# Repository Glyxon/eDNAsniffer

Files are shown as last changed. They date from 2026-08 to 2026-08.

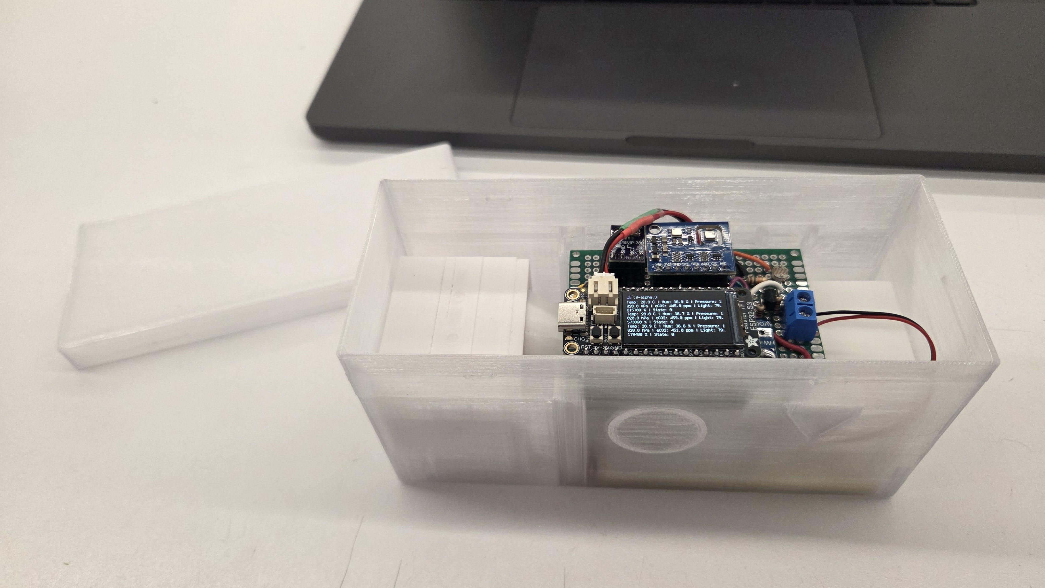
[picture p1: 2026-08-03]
ESP32 Assembly pics/signal-2026-08-01-16-24-59-932_003.jpg

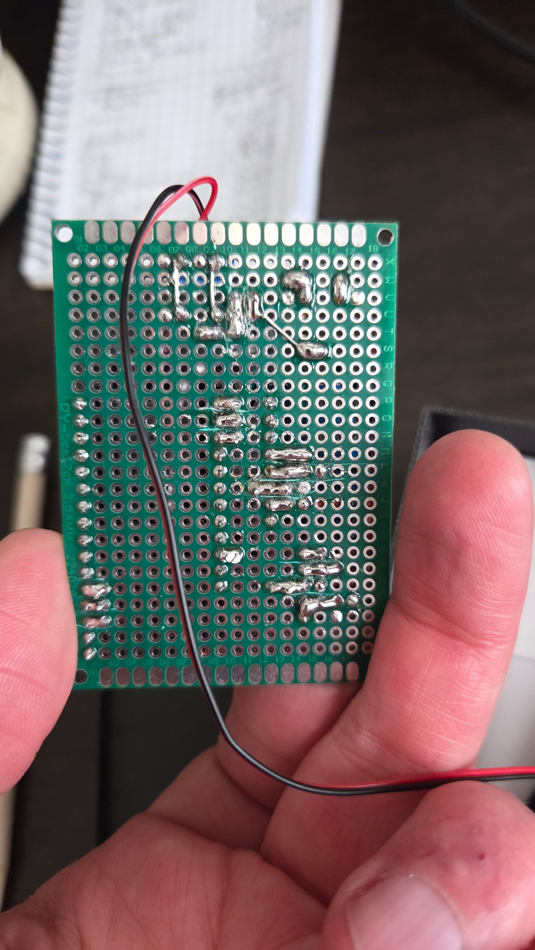
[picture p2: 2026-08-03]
ESP32 Assembly pics/wiring2.jpg

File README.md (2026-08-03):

# eDNA Sniffer (v1.1)

An open-source, low-cost, ESP32-S3/ Rapsberry-Pi powered airborne environmental DNA (eDNA) sampling and monitoring station. 

Developed as part of decentralized biotechnology and open hardware initiatives (Developed by **Glyxon BioLabs** and **BioOlympia**), this project integrates physical air filtration, environmental sensor telemetry (temperature, humidity, pressure, gas quality, and light), and a streamlined molecular biology protocol for downstream 16S rRNA gene amplification and taxonomic profiling. This project is presented at DEFCON 34. 

Contact the creators: 

Dr. David Castillo · glyxonbiolabs@gmail.com  ·  +52 (55) 4140 7607
BioOlympia (Matt + Zee) · BioOlympia@gmail.com  ·  +1 (971) 319-2665



---

## 🛠️ System Overview & Architecture

The eDNA Sniffer combines an **ESP32 microcontroller** (Ideaspark board) with an environmental sensor hub, an air sampling chamber driven by a brushless fan, and an optimized dual-capture physics configuration.

```
[Air Intake] → [Membrane Filter / Fine Mesh] → [3010 Fan] → [Silica Gel Chamber] → [Air Exhaust]
```

**Airflow Diagram (Sampling Enclosure)**



To build the physical collector using your boards and the fan, you need to design or adapt a small airtight container (this could be a 3D-printed enclosure or a modified plastic container):

1.	The fan pulls or pushes outdoor air, forcing it through a small chamber (Venturi collector)  where you position your eDNA collection membrane.
2.	The filtered, dried air then flows past rate is monitored by different sensors (AHT21/BME280 and ENS160) to log precise environmental sampling parameters (humidity, background volatile organic compounds, and temperature).

Implementing a dual-capture mechanism within this Venturi geometry leverages fluid dynamics beautifully to sort particles by size and mass. In aerosol science and environmental sampling, this is conceptually similar to a simplified cascade impactor.
Here is how the physics of this dual-capture setup benefits your eDNA sampling:
1. Intake Pre-Filter (Coarse eDNA Capture)
•	The Mechanism: At the wide base, the air velocity entering from the 3010 fan is relatively slow, but the surface area is at its largest.
•	What it Captures: Large biological vectors such as whole pollen grains, fungal spores, insect fragments, and heavy environmental dust particles that contain cellular material.
•	The Benefit: It acts as a primary filter. If these massive particles reached the narrow throat or the fine filter, they would immediately clog the system (causing severe back pressure) and reduce the sampler's operational lifespan in the field.

2. Venturi Throat / Upper Trap (High-Velocity Fine eDNA Capture)
•	The Mechanism: As the air is forced through the constriction, its velocity peaks.
•	What it Captures: Micro-droplets, fine aerosolized particles, single bacteria, and naked/free-floating extracellular DNA strands bound to microscopic dust (PM2.5 or smaller). The higher momentum allows these tiny particles to be driven forcefully into a fine-pore membrane (like glass fiber or nylon).
•	The Benefit: This is where you isolate the highly integrated, long-range eDNA signals traveling through the air mass rather than just localized debris.
How to Read Sensors in this Dual Setup
By utilizing the different sensor placement options shown in the diagram, you can monitor the physical performance of this dual-capture chamber in real-time with your ESP32:
•	Monitoring Clogging (Differential Pressure): If you place the BME280/BMP280 at Location 2 (Venturi Throat) or Location 1 (Post-Filter), you can track the static pressure drop over time. As filters capture eDNA and start to saturate, the pressure values will shift drastically. When the pressure drop levels off or hits a critical threshold, the ESP32 LCD can alert you that the filters are full and the device has completed its run.
•	Correlating Environmental Data: The ENS160 gas readings (eCO2/TVOC) will help you cross-reference your biological collection with environmental context—letting you know if a high yield of eDNA correlates with sudden spikes in organic volatiles or stale air masses.

### Key Hardware Components











* **Microcontroller:** ESP32-S3 FT Feather  (Adafuit development board with built-in display).
* **Air Sampling Mechanism:** 3010 Brushless Fan (5V) paired with a Venturi geometry sampling chamber.
* **Desiccant Chamber:** Indicating silica gel to maintain low humidity and prevent DNA degradation post-collection.
* **Capture Media:** Nitrocellulose filter paper (0.2 to 1 µm) for fine eDNA trapping, supported by optional bacterial cellulose matrices (`Komagataeibacter xylinus`) can be provided by Glyxon BioLabs if you need some.

2. Sensor Connection Architecture (I2C)
Both the ENS160+AHT21 module and the BME280/BMP280 operate primarily via the I2C communication protocol. This means they can share the same data (SDA) and clock (SCL) lines, drastically simplifying the circuit layout on your green prototyping PCB.
Pin Mapping (ESP32 Ideaspark):
By default, most ESP32 boards configure the I2C protocol on the following pins, though you can redefine them in your Arduino dependencies.

Watch out for I2C addresses! If your pressure chip turns out to be a BMP280 instead of a BME280, keep in mind that its default I2C address usually shifts between 0x76 and 0x77. The ENS160 typically uses address 0x53. They will not collide on the bus.
The LDR (GL5516 Light Sensor):
To measure ambient light, you need to build a voltage divider using one of your 10kΩ resistors. This translates the varying resistance of the LDR into a voltage the ESP32 can read:
1.	Connect one end of the LDR to 3.3V.
2.	Connect the other end of the LDR to an analog pin on the ESP32 (e.g., GPIO 34 or 35).
3.	From that same middle connection point, connect a 10kΩ resistor to GND.

Controlling the Fan (3010 Fan):
The fan runs on 5V. Do not connect it directly to an ESP32 data pin because you will burn out the chip (ESP32 pins only output 3.3V and about 20-40mA).
•	Simple Option: Connect it directly to the 5V/VIN and GND pins on the ESP32 so that it draws air continuously as soon as the system powers up.

---

## 🔌 Wiring & Pin Mapping

Both sensor modules operate on the **I2C protocol**, allowing them to share a common data bus (`SDA` on GPIO 21, `SCL` on GPIO 22).

### Complete Wiring Matrix

| Component | Pin | Connects To (ESP32) | Purpose / Notes |
| :--- | :--- | :--- | :--- |
| **ENS160+AHT21 Module** | `VCC` | `3V3` | 3.3V Power Supply |
| | `GND` | `GND` | Common Ground |
| | `SCL` | `GPIO 22` | I2C Clock Line (Shared) |
| | `SDA` | `GPIO 21` | I2C Data Line (Shared) |
| **BME280/BMP280 Module** | `VCC` | `3V3` | 3.3V Power Supply |
| | `GND` | `GND` | Common Ground |
| | `SCL` | `GPIO 22` | I2C Clock Line (Shared) |
| | `SDA` | `GPIO 21` | I2C Data Line (Shared) |
| **GL5516 Photoresistor (LDR)** | `Pin 1` | `3V3` | Voltage Source |
| | `Pin 2` | `GPIO 34` | Analog Input & Divider Junction |
| **10kΩ Resistor** | `Lead A` | `GPIO 34` | Connected to Ldr Pin 2 |
| | `Lead B` | `GND` | Pulls signal to Ground |
| **3010 Brushless Fan (5V)** | `Red Wire` | `5V / VIN` | Direct power from USB/Power Bank source |
| | `Black Wire` | `GND` | Continuous ground connection |

> ⚠️ **Important Safety Check:** Keep the 5V brushless fan strictly connected to the `5V / VIN` pin. Connecting 5V inductive loads directly to the 3.3V digital rail can permanently damage the ESP32 internal voltage regulator.

---

## 💻 Firmware & Arduino IDE Setup

Basic Code Logic (Arduino IDE)
For ESP32 boards with built-in LCD screens, you will need to install these libraries from the Arduino Library Manager:
•	Adafruit BME280 Library (or BMP280)
•	ScioSense_ENS160 (for the advanced air quality sensor)
•	Specific graphics libraries for your Ideaspark display (usually TFT_eSPI or Adafruit_GFX, depending on the exact LCD model it uses).

### Required Libraries
Install the following libraries via the Arduino Library Manager:
1. `Adafruit BME280 Library` (or BMP280)
2. `ScioSense ENS160` (for eCO2 and TVOC air quality metrics)
3. TFT / GFX graphics libraries compatible with your specific Ideaspark display.

Recommended Steps
•	Identify the pressure sensor: Use a magnifying glass to check the tiny silver pressure chip. If it is tiny and perfectly square with 4 internal pins, it is a BME280 (it measures humidity). If it is rectangular, it is a BMP280. Knowing this will let you fine-tune the code.
•	Field Power Supply: Since this is an environmental sampling device, you will need a portable power source. The ESP32 draws a fair amount of current if Wi-Fi is active, but by keeping it turned off or using a standard 5V power bank connected to the USB port, you can easily run both the microcontroller and the fan during your field trips.

To connect all your components together safely using your green prototyping PCB, you can map out your wiring based on the functional groups.
Because the ESP32 operates on 3.3V logic, we must power the logic lines of the sensors with 3.3V, while running the 5V fan directly from the main power input pin (5V or VIN).

### Basic Sketch Template
```cpp
#include <Wire.h>
#include <Adafruit_Sensor.h>
#include <Adafruit_BME280.h> // Change to BMP280 if needed
#include <ScioSense_ENS160.h>

Adafruit_BME280 bme;
ScioSense_ENS160 ens160(ENS160_I2CADDR_0); // Typical address 0x53

const int ldrPin = 34; // Analog pin for light sensor

void setup() {
  Serial.begin(115200);
  Wire.begin(21, 22); // Initialize I2C on pins 21 (SDA) and 22 (SCL)
  
  if (!bme.begin(0x76)) {
    Serial.println("Could not find a valid BME280/BMP280 sensor!");
  }
  if (!ens160.begin()) {
    Serial.println("Could not find a valid ENS160 sensor!");
  }
  ens160.setMode(ENS160_OPMODE_STANDARD);
}

void loop() {
  // 1. Read basic environmental data
  float temp = bme.readTemperature();
  float pres = bme.readPressure() / 100.0F;
  float hum = bme.readHumidity(); 

  // 2. Read air quality
  if (ens160.available()) {
    ens160.measure(true);
    uint16_t eco2 = ens160.getECO2();
    uint16_t tvoc = ens160.getTVOC();
    Serial.printf("eCO2: %d ppm | TVOC: %d ppb\n", eco2, tvoc);
  }

  Serial.printf("Temp: %.2f°C | Pres: %.2fhPa | Hum: %.2f%%\n", temp, pres, hum);

  // 3. Read ambient light
  int lightRaw = analogRead(ldrPin);
  Serial.printf("Light (Raw): %d\n", lightRaw);

  delay(2000);
}
```

Prototyping PCB Layout Instructions
When soldering these pieces onto a Mingjinda Electronics perfboard, follow these spatial layout and structural tips:
1. Create Power and Ground Rails
Dedicate two long continuous rows of holes on your PCB to act as your Power Rails.
•	Run a jumper wire from the ESP32 3V3 pin to your positive rail.
•	Run a jumper wire from the ESP32 GND pin to your negative ground rail.
•	Connect the VCC and GND pins of all your sensors directly to these rails.

The Shared I2C Bus
You do not need separate pins on the ESP32 for your two sensor boards. Solder a wire connecting the SDApin of the ENS160 to the SDA pin of the BME280, then run a single wire from that junction to GPIO 21. Do exactly the same for the SCL pins, running them to GPIO 22.
3. Assembling the LDR Circuit
Solder one leg of the photoresistor and one leg of your 10kΩ resistor into the same electrical track (or bridge them with solder). From that exact same joint, run a wire to GPIO 34. Connect the remaining free leg of the photoresistor to your 3V3 rail, and the remaining free leg of the resistor to your GND rail.
⚠️ Important Safety Check: Ensure your brushless fan wires do not accidentally touch the 3.3V rail. Connecting a 5V inductive load directly to the 3.3V digital rail can permanently destabilize or burn out the ESP32 inner voltage regulator. Keep the fan connections strictly on the 5V/VIN pin.


https://github.com/user-attachments/assets/008a1193-c7c1-4f29-b75c-39778a0f0ac4





---

## 🧬 Downstream Molecular Workflow (16S eDNA)

Captured air filters undergo standard molecular processing to extract and amplify bacterial communities:

1. **Harvesting & Lysis:** Section the nitrocellulose filter using sterile tools. Apply a co-extraction strategy (mild detergent incubation followed by short 30s bead-beating) to release intracellular DNA from spores without destroying free extracellular strands.
2. **Purification:** Use a silica spin-column architecture (e.g., Omega Bio-tek) via **Bind-Wash-Elute** protocols to clear airborne PCR inhibitors (soot, humic acids).



DNA retrieval and amplification of target sequences
To analyze bacterial communities from an environmental air sampler, the workflow follows a standard molecular biology pipeline: converting the physical sample into purified nucleic acids, followed by targeted enzymatic amplification.
Because you are targeting the 16S rRNA gene (a universal phylogenetic marker for prokaryotes), the protocol focuses on total community DNA extraction rather than isolating specific living cultures.



0.2um filters

Phase 1: Sample Retrieval & Mechanical Lysis
Environmental samples on nitrocellulose filters typically contain low biomass and robust structures like bacterial cell walls or spores. Efficient lysis is critical to obtaining a representative yield.
•	Filter Harvesting: Using sterile forceps in a clean laminar flow hood, remove the nitrocellulose filter from the Venturi sampler.
•	Sectioning: Cut the filter into smaller pieces using a sterile scalpel blade to ensure it fits entirely within the lysis vessel (typically a 2 mL bead-beating tube).
•	Lysis Buffer & Homogenization: Add the specialized lysis buffer provided in your Omega Bio-tek isolation kit. For environmental samples, mechanical disruption such as bead beating or vortexing with silica/zirconia beads is highly recommended alongside chemical lysis to break open tough Gram-positive cell walls and spores.

Phase 2: Total DNA Purification (Omega Bio-tek Kit Principles)
Commercial kits typically utilize a silica spin-column architecture based on a "Bind-Wash-Elute" mechanic:
1.	Clearing the Lysate: After homogenization and centrifugation, the crude lysate is separated from the filter debris and unlysed particulates. The supernatant containing the solubilized DNA is transferred to a clean tube.
2.	Binding: An adjustment buffer (usually containing chaotropic salts and ethanol) is added to the lysate. This condition forces the DNA backbone to bind selectively to the silica membrane inside the spin column when centrifuged.
3.	Washing: The bound DNA is washed with alcohol-based wash buffers provided in the kit. This step removes residual proteins, cellular metabolites, metabolic byproducts, and potential PCR inhibitors collected from the ambient air.
4.	Elution: After drying the membrane completely via an empty centrifugation step, a low-salt elution buffer (or sterile nuclease-free water) is applied. This releases the purified total genomic DNA (gDNA) into a clean collection tube.
Phase 3: 16S rRNA PCR Amplification
With the total gDNA purified, you can target the hypervariable regions of the bacterial 16S rRNA gene. Because you are using Pfu DNA Polymerase (a high-fidelity, proofreading enzyme) instead of standard Taq, note that it requires specific reaction conditions (such as longer extension times and blunt-end generation).



3. **Amplification (Pfu Polymerase):** Target the universal 16S rRNA gene (approx. 1.5 kb using 27F/1492R primers) with high-fidelity Pfu DNA Polymerase.
   * *Initial Denaturation:* 95°C for 2–5 min
   * *30–35 Cycles:* 95°C (30s) → 52–55°C (30s) → 72°C (2–3 min extension)
   * *Final Extension:* 72°C for 5–10 min
4. **Verification:** Run a 5 µL aliquot on a 1% agarose gel to confirm a clean target band at ~1,500 bp.

---

## 📊 Bioinformatics & Taxonomic Analysis

* **Quality Control:** Inspect reads using **FastQC** (filter Q-scores < 15).
* **Alignment & Classification:** Utilize free open-source reference databases (**SILVA** or **GreenGenes2**) via local tools like **QIIME 2** / **DADA2** or cloud platforms like **Galaxy**.
* **Visualization:** Generate relative abundance stacked bar charts, homology heatmaps, and phylogenetic trees via **ITOL** or **Microreact**.





---

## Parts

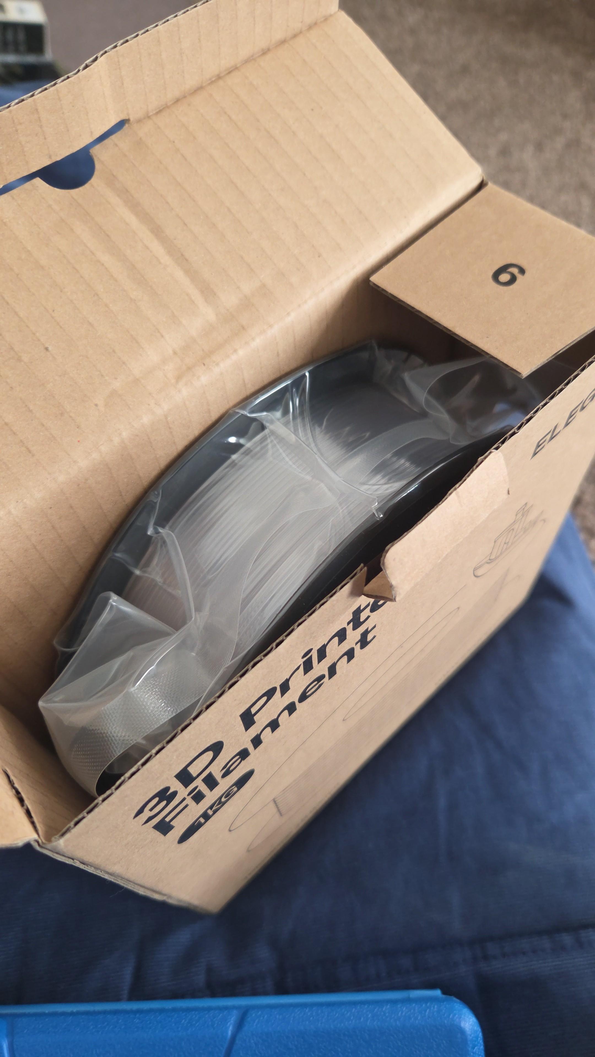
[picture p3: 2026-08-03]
ESP32 Assembly pics/3DprintingmaterialPETG.jpg

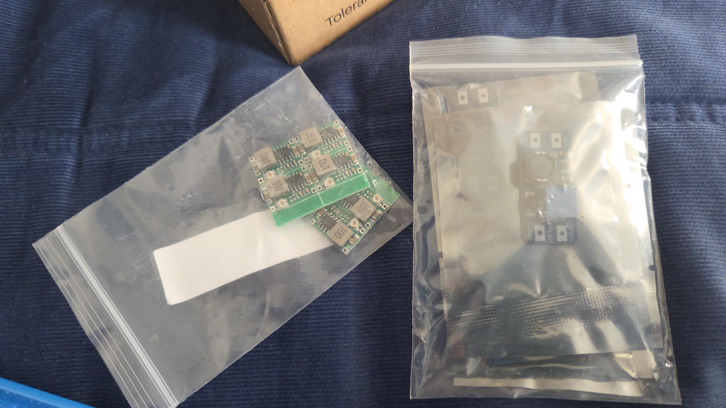
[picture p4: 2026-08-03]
ESP32 Assembly pics/components .jpg

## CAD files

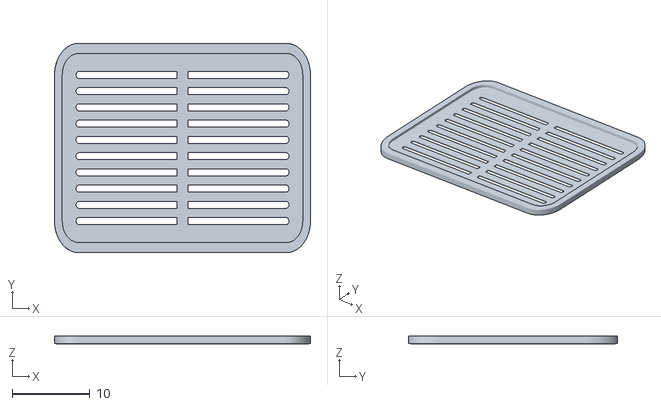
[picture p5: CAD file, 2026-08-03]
eDNA Sinffer :Venturi 3D printing files/silica spacer.stl
33.0 x 27.0 x 1.00

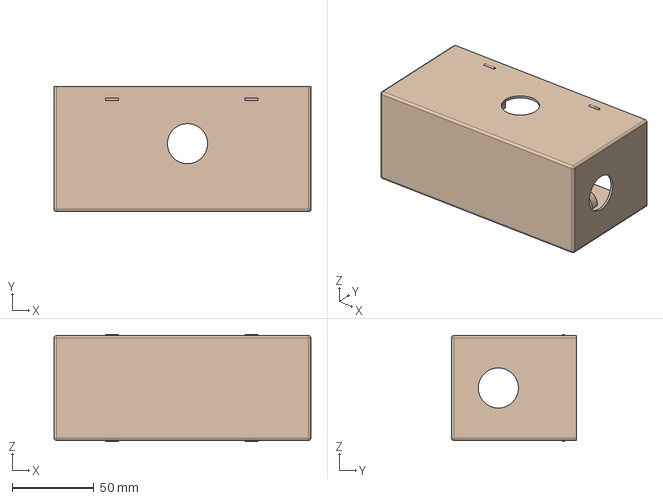
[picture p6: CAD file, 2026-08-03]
Housing 3D printing files/Box.step
156.9 x 76.5 x 65.5 mm

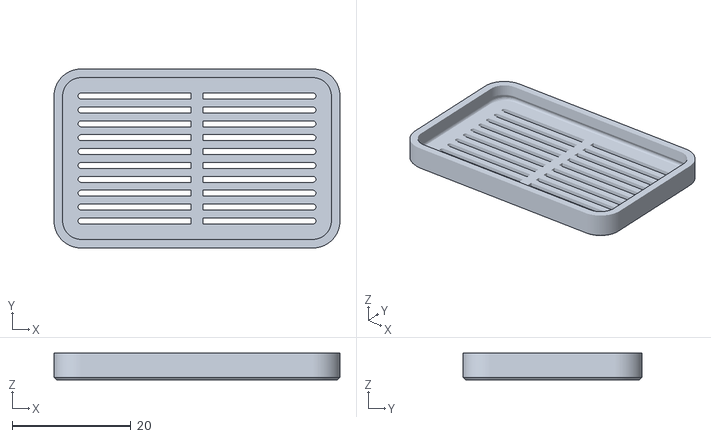
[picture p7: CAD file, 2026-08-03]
eDNA Sinffer :Venturi 3D printing files/AMS%20Dryer%20pod%20indent%20lid.stl
48.1 x 30.1 x 4.50

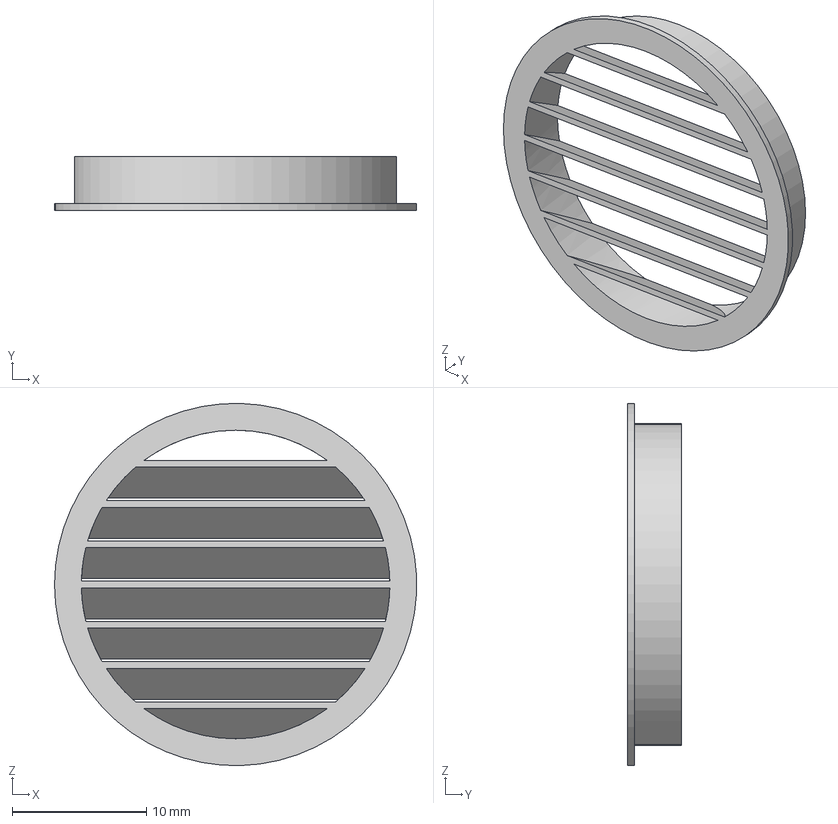
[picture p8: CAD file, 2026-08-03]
Housing 3D printing files/Vent_Circle.step
27.0 x 4.00 x 27.0 mm

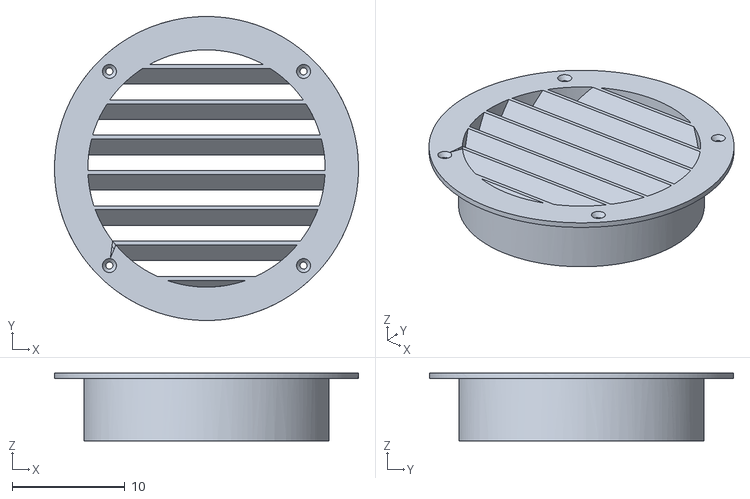
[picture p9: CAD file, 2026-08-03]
eDNA Sinffer :Venturi 3D printing files/end exhaust.stl
27.0 x 27.0 x 6.00

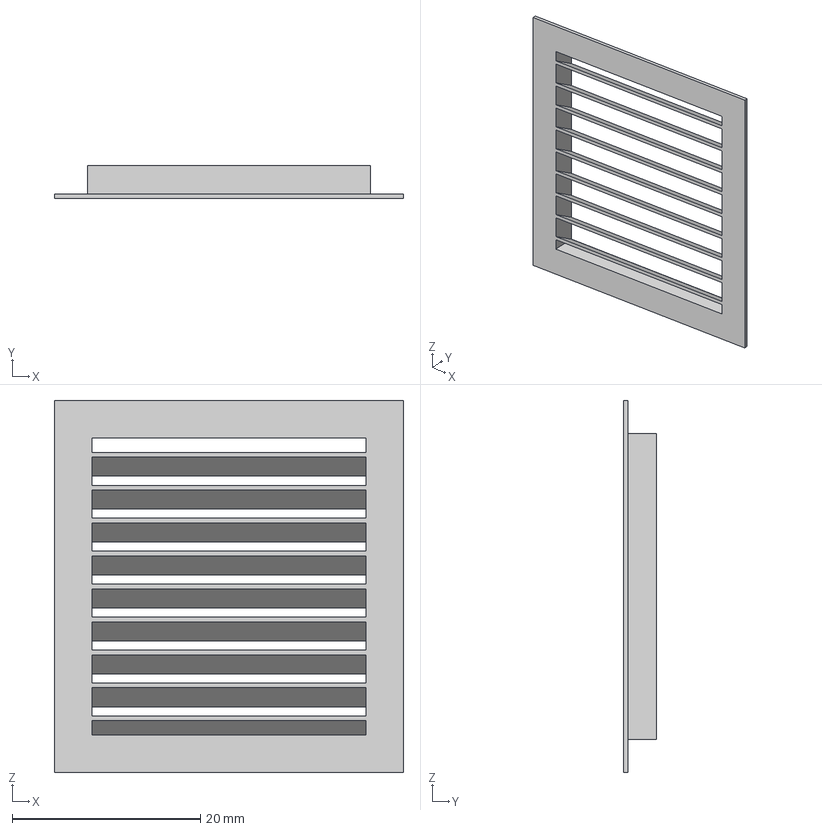
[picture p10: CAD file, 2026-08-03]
Housing 3D printing files/Vent Square.step
37.1 x 3.50 x 39.5 mm

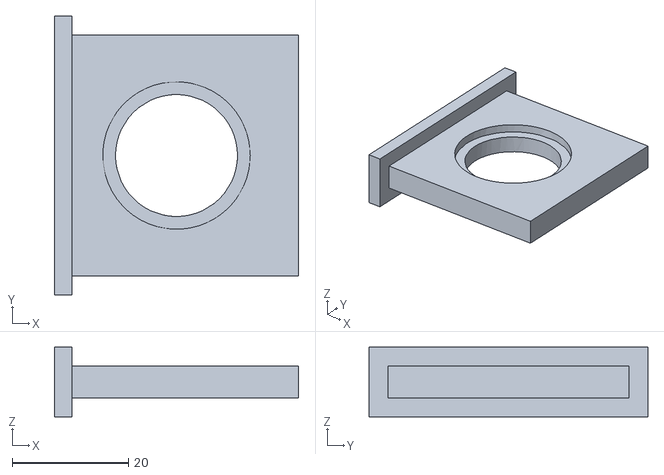
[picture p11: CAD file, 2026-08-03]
eDNA Sinffer :Venturi 3D printing files/25mm filter holder.stl
42.0 x 48.0 x 12.0

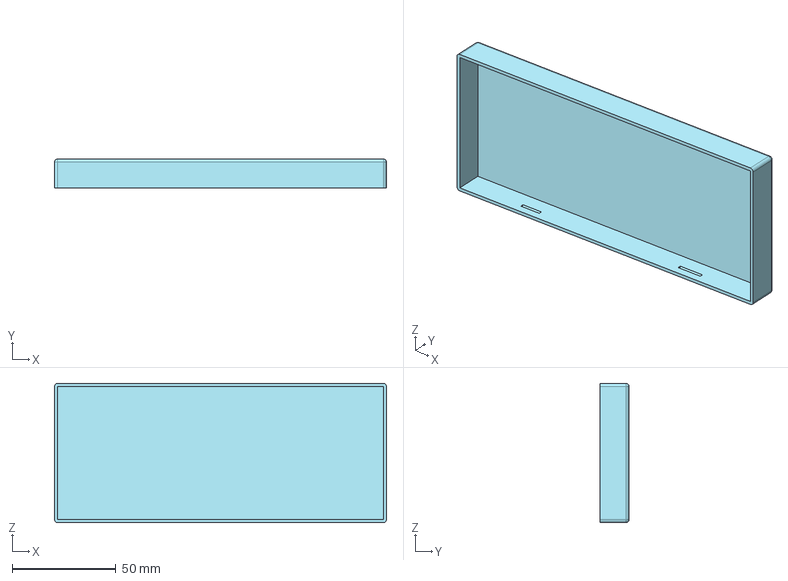
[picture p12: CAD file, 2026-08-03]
Housing 3D printing files/Lid.step
160.0 x 14.0 x 67.1 mm

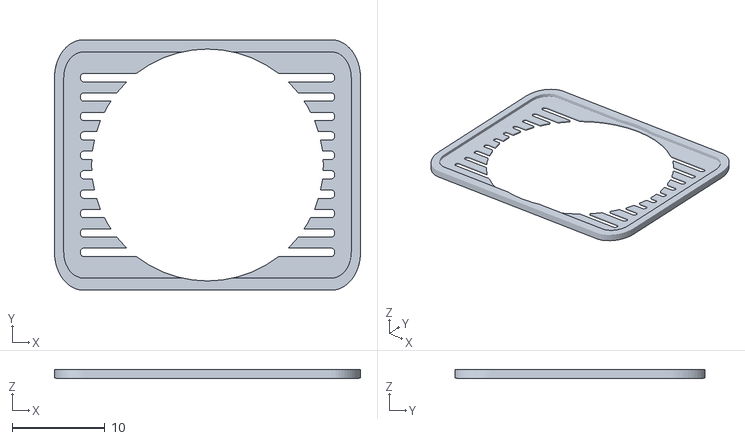
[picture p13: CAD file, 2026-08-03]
eDNA Sinffer :Venturi 3D printing files/filter holder2-silica.stl
33.0 x 27.0 x 1.00

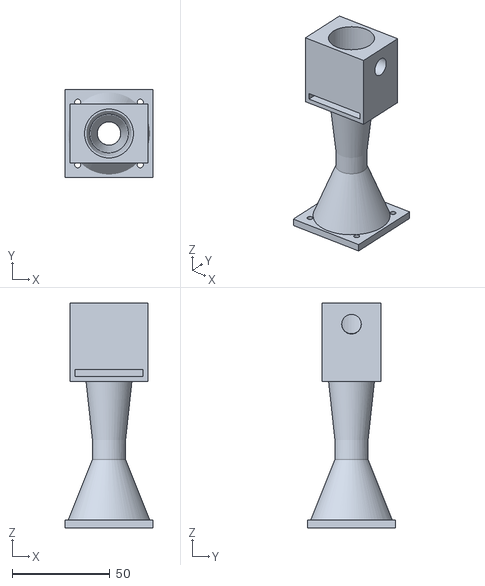
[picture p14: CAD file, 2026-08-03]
eDNA Sinffer :Venturi 3D printing files/venturibody.stl
45.0 x 45.0 x 115.0

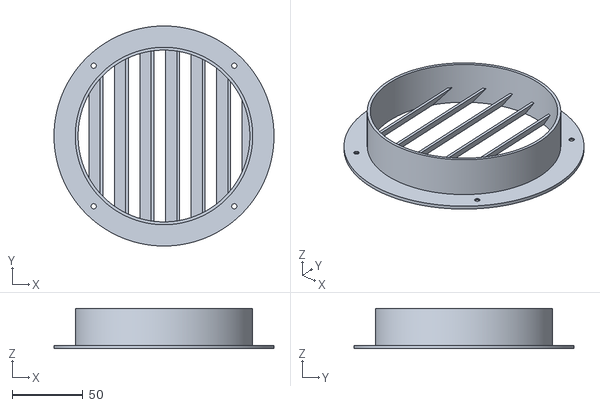
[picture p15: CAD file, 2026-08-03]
eDNA Sinffer :Venturi 3D printing files/ventilation-grille.stl
155.0 x 155.0 x 28.2

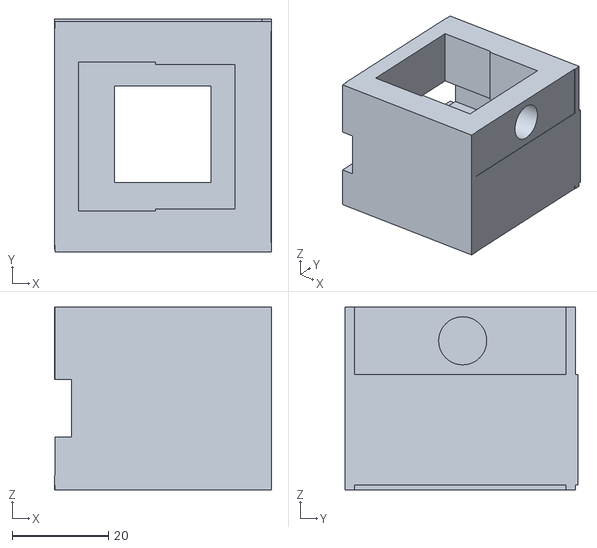
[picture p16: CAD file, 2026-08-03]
eDNA Sinffer :Venturi 3D printing files/Fan chamber 1.stl
45.1 x 48.5 x 38.0

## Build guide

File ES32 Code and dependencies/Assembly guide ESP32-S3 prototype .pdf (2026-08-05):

# Technical Manual: Assembly, Firmware, and

## eDNA Protocol BioOlympia/GlyxonBiolabs

Bio-Sniffer V3.0: Autonomous Environmental DNA Capture & Multivariable Instrumentation

Technical Manual, CAD Assembly & eDNA Protocol

Open-Source Environmental Monitoring Network for Permafrost eDNA Capture & Pathogen Surveillance

- Microcontroller: Adafruit Feather ESP32-S3 TFT
- Firmware Stack: CircuitPython Core (FSM)
- Release Date: August 2026

### 1. Scientific Context & Threat Matrix (Permafrost eDNA)

Accelerated climate change in polar and subpolar latitudes causes rapid thawing of permafrost. This exposes ancient organic layers containing dormant microorganisms, viral particles, and preserved environmental DNA (eDNA). The Bio-Sniffer V4.0 is engineered as a decentralized, low-cost monitoring node designed to capture airborne bioaerosols and eDNA fragments originating from thawing polar soils before community exposure occurs.

Key Case Studies in Literature

- Siberian Anthrax Outbreak (Yamal, 2016): Heatwaves thawed an infected reindeer carcass frozen since 1941, releasing viable Bacillus anthracis spores that caused widespread reindeer mortality and human hospitalizations.
- Giant Viruses Revival (2014–2015): Isolation of viable Pithovirus sibericum and Mollivirus sibericum from over 30,000-year-old Siberian permafrost layers.
- Pandoravirus yedoma (2023): Recovery of infectious viral particles and intact genomic material from permafrost cores dating back over 48,500 years.

### 1. Executive Summary and Venturi Hydrodynamic Architecture

The Bio-Sniffer eDNA is a decentralized, open-hardware device designed for active suction, physical capture of airborne environmental DNA, and multivariable microclimatic telemetry. The prototype's core integrates an Adafruit Feather ESP32-S3 TFT microcontroller mounted on a perforated PCB development board, featuring I2C sensors, ambient luminance reading, and dual LiPo autonomous power management.

Its mechanical architecture employs a hydrodynamic "Venturi effect" to create a constant negative pressure zone in the suction throat via a 3010mm 5V DC axial blower. Ambient air flows from the intake nozzle, passing through a multi-stage filtration system combining coarse mechanical retention and a 25mm (0.22 µm) membrane filter, and is channeled toward a desiccant chamber with silica gel to prevent enzymatic/hydrolytic degradation of the captured nucleic acids. Physical separation isolates the thermal sensor modules from the heat emitted by the CPU and the Feather's IPS TFT screen.

### 2. Complete Bill of Materials (BOM)

### 2.1 Electronic Components and Power

Component | Specification / I2C Address / Pin | Q
ty. | System Function
Main MCU | Adafruit Feather ESP32-S3 TFT (Dual
| Core, IPS Display) | 1

Processing, FSM state machine, TFT screen.

### 2.2 Mechanical Parts and 3D Prints

LiPo Batteries | Qimoo 606090 3.7V 4000mAh (JST
PH2.0mm) | 2

Parallel power supply for extended autonomy.

Terminal Blocks | Dual screw terminals salvaged from
MOSFET module | 2 | Interconnection and mechanical distribution of the power bus.

Boost Converter
Module

MT3608 DC-DC Step-Up (Pre-

calibrated to 5.0V) | 1 | Conversion from 3.7V LiPo to 5.0V for the
| | axial blower.

MOSFET
Driver

N-Channel MOSFET (2N7000/
IRFZ44N) + 10k Pull-down | 1 | Fan switching from GPIO26/D5.

Air Quality
Sensor

ENS160 + AHT21 (I2C: 0x53/0x38)
1

Measurement of eCO2, TVOC, Temperature, and Relative Humidity.

Barometric
Sensor

BMP280 Barometric (I2C: 0x76) 1 Measurement of atmospheric pressure and altitude.

LiPo Fuel
Gauge

MAX17048 Fuel Gauge (I2C: 0x36) 1 Direct monitoring of battery percentage and voltage.

Luminance
Sensor

GL5516 Photoresistor + 10k Resistor
(Pin A0) | 1

Voltage divider for ambient light reading.

Axial Fan | 3010mm DC 5V (Connected to MT3608
VOUT+) | 1

Generation of active Venturi suction flow.

3D File | Format | Material | Structural Description and Function
venturibody.stl | STL/ STEP | PETG/ PLA | Acceleration throat and main body for the Venturi effect.
Fan chamber 1.stl | STL/ STEP | PETG/ PLA | Internal chamber for the 3010mm blower and assembly rack.

CRITICAL POWER CALIBRATION WARNING Before soldering or connecting the VOUT+/VOUT- output of the MT3608 step-up module to the 3010mm fan or the Feather ESP32-S3, power the module with the 3.7V battery and turn the fine potentiometer with a multimeter until it measures exactly 5.0V DC. Uncalibrated voltage will destroy the blower or overheat the electronics.

25mm filter holder.stl | STL/
STEP

PETG/
TPU Retaining support for the fine membrane disk (0.22 µm).
main_outer_enclosure.stl | STL/
STEP | PETG/
ABS | Translucent outer chassis with ventilation grilles.
end exhaust.stl | STL/
STEP

PETG/
PLA | Rear exhaust and air flow expulsion nozzle.
AMS Dryer pod indent lid.stl | STL/
STEP

PETG/
PLA | Sealed top cover/lid for the desiccant bay.
filter holder2-silica.stl | STL/ STEP
PETG/
TPU

Intermediate grille and container for silica gel beads.

## 3. Wiring Diagram and Electrical Schematic

-------------------------------------------------------------------------CONNECTION DIAGRAM AND BUSES (BIO-SNIFFER V3.0) -------------------------------------------------------------------------

[2x Qimoo 3.7V 4000mAh Battery] --(JST PH2.0)--> [Salvaged MOSFET Terminals] |
+--- (VIN 3.7V)
[MT3608 Step-Up]
(Adjust to 5.0V)
(5V Out+)---+----------------+
[3010 Fan (+)] | [3.3V]
[10k Ohm]
[Adafruit Feather ESP32-S3 TFT Pinout] | +--> [LDR GL5516]
├── 3.3V ---------> VCC Bus (BMP280 / ENS160+AHT21 / MAX17048) | |
├── GND | ---------> Common GND (LiPo, MOSFET, Modules, LDR) <------+
├── SDA ---------> Shared I2C SDA [0x76, 0x53, 0x38, 0x36]
├── SCL | ---------> Shared I2C SCL [0x76, 0x53, 0x38, 0x36]
├── A0 | ---------> LDR GL5516 Voltage Divider
└── D5/GPIO26 ----> [10k Ohm] -> Gate MOSFET (2N7000 / IRFZ44N)
│
+--> [10k Pull-Down] -> GND
│
Drain -> [3010 Fan (-)]
Source -> Common GND

## 4. CircuitPython Firmware Architecture (Finite State Machine)

The control code is structured as a non-blocking Finite State Machine (FSM) running on CircuitPython Core for the Feather ESP32-S3 TFT, divided into 3 primary states:

- STATE_IDLE (0): Passive monitoring loop. Samples the I2C sensors (BMP280, ENS160, AHT21, LDR, MAX17048) every 5 seconds. Evaluates the biological alert window: Temperature≤30.0∘C ANDRelative Humidity≥55.0%. If met, switches to STATE_SAMPLING.

- STATE_SAMPLING (1): Activates the GPIO pin (D5) HIGH (3.3V), exciting the MOSFET gate and starting fan suction at 5V. Maintains active capture for a strict interval of 20 seconds (SAMPLING_DURATION). Features a hysteresis abort rule (Temp>31.5∘C or Hum<52.0%). Upon completion, turns off the fan and transitions to STATE_COOLDOWN.
- STATE_COOLDOWN (2): Hardware lockout period of 10 seconds (COOLDOWN_DURATION) to prevent rapid fluctuations, overheating, and allow sensor stabilization before returning to STATE_IDLE.

### 4.1 Main Source Code (code_climate_fsm.py)

(Python)

import time
import board
import digitalio
from analogio import AnalogIn import adafruit_bmp280
import adafruit_ahtx0
import adafruit_ens160
import adafruit_max1704x

# Pinout & Hardware

FAN_PIN = board.D5
PHOTORESISTOR_PIN = board.A0
i2c = board.STEMMA_I2C()
pressure_sensor = adafruit_bmp280.Adafruit_BMP280_I2C(i2c, 0x76) temp_hum_sensor = adafruit_ahtx0.AHTx0(i2c)
gas_sensor = adafruit_ens160.ENS160(i2c)
battery_sensor = adafruit_max1704x.MAX17048(i2c)

fan = digitalio.DigitalInOut(FAN_PIN) fan.direction = digitalio.Direction.OUTPUT fan.value = False
light_sensor = AnalogIn(PHOTORESISTOR_PIN)

# Thresholds & Timing

TEMP_MAX_THRESHOLD = 30.0
HUM_MIN_THRESHOLD = 55.0
HYSTERESIS_TEMP = 1.5
HYSTERESIS_HUM = 3.0
POLL_INTERVAL = 5.0
COOLDOWN_DURATION = 10.0
SAMPLING_DURATION = 20.0

STATE_IDLE, STATE_SAMPLING, STATE_COOLDOWN = 0, 1, 2 current_state = STATE_IDLE
prev_t = time.monotonic()
cooldown_start = 0.0
sampling_start = 0.0

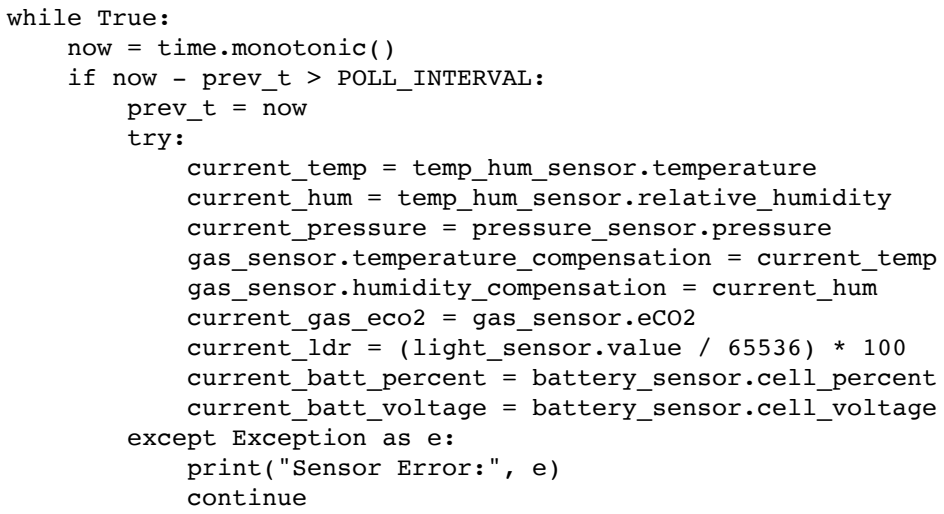
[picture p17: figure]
while True: now = time.monotonic() if now - prev_t > POLL_INTERVAL: prev_t = now try:; current_gas_eco2 = gas_sensor.eCO2; except Exception as e: print("Sensor Error:", e) continue

current_temp = temp_hum_sensor.temperature current_hum = temp_hum_sensor.relative_humidity current_pressure = pressure_sensor.pressure gas_sensor.temperature_compensation = current_temp gas_sensor.humidity_compensation = current_hum

current_ldr = (light_sensor.value / 65536) * 100 current_batt_percent = battery_sensor.cell_percent current_batt_voltage = battery_sensor.cell_voltage

print("Temp: %.1f C | Hum: %.1f %% | eCO2: %.1f ppm | Light: %.2f %%"
%
(current_temp, current_hum, current_gas_eco2, current_ldr))

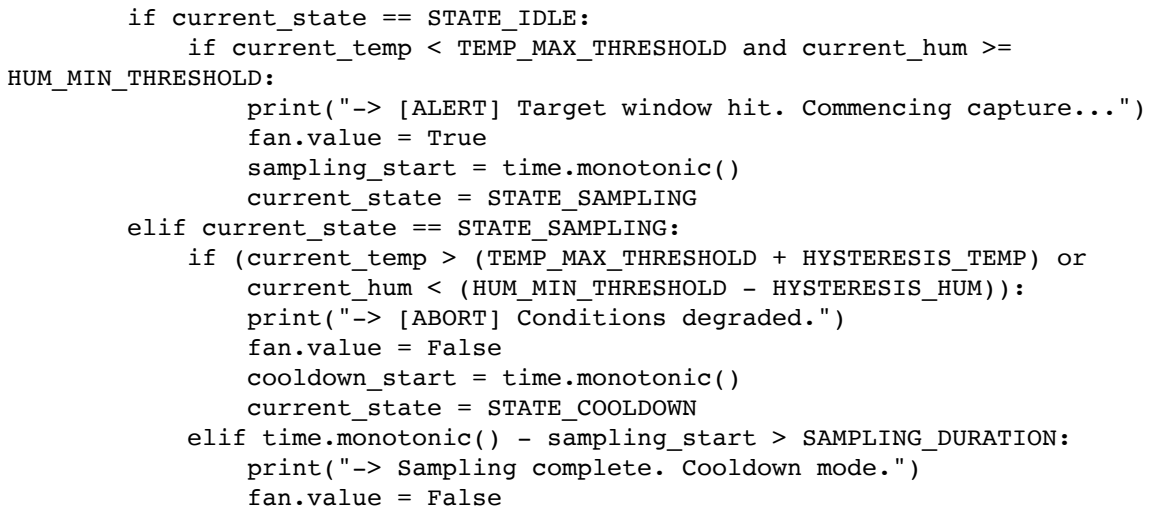
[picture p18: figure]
if current_state == STATE_IDLE:; HUM_MIN_THRESHOLD:; fan.value = True sampling_start = time.monotonic() current_state = STATE_SAMPLING elif current_state == STATE_SAMPLING:; fan.value = False cooldown_start = time.monotonic() current_state = STATE_COOLDOWN; fan.value = False

if current_temp < TEMP_MAX_THRESHOLD and current_hum >=

print("-> [ALERT] Target window hit. Commencing capture...")

if (current_temp > (TEMP_MAX_THRESHOLD + HYSTERESIS_TEMP) or current_hum < (HUM_MIN_THRESHOLD - HYSTERESIS_HUM)): print("-> [ABORT] Conditions degraded.")

elif time.monotonic() - sampling_start > SAMPLING_DURATION: print("-> Sampling complete. Cooldown mode.")

cooldown_start = time.monotonic()
current_state = STATE_COOLDOWN
elif current_state == STATE_COOLDOWN:
if time.monotonic() - cooldown_start > COOLDOWN_DURATION: print("-> Cooldown done. Re-entering IDLE.") current_state = STATE_IDLE

## 5. Recovery, Genomic Lysis, and 16S rRNA Analysis Workflow

- STEP 1: Filter and Mesh Recovery

Upon completing the active suction cycle, remove the AMS Dryer pod indent lid.stl cover and the silica tray. Using sterilized tweezers, extract the 25mm fine nylon/nitrocellulose membrane disk from 25mm filter holder.stl (Fine Filter) and the coarse pre-filter mesh. Place the fine filter in Tube A and the pre-filter in Tube B with Pre-Lysis Buffer.

- STEP 2: Protocolized Total DNA Extraction

Add Lysis Buffer to the samples. Vortex vigorously to detach the eDNA biomass adhered to the fibers. Incubate at 65∘C for enzymatic digestion and cell lysis. Centrifuge at high speed to precipitate solid debris ("pellet debris"). Pass the purified supernatant through a silica affinity column, apply Wash Buffer, and elute the concentrated eDNA.

- STEP 3: 16S rRNA Molecular Marker and Bioinformatic Identification

For taxonomic characterization of captured bacterial and archaeal communities, the gene encoding the 30S ribosomal subunit is amplified (16S rRNA, ~1500 bp):

- Conserved Regions: Universal primer binding sites ensuring multi-specific amplification.
- Hypervariable Regions (V1-V9): Variable genomic segments acting as a "fingerprint" to differentiate genera and species with high resolution.

- Bioinformatic Alignment: Sequencing reads are compared using bioinformatic pipelines against curated databases (SILVA, GTDB, EzBioCloud, NCBI). This flow enables the identification of extremophilic/polar species or infiltrated permafrost bacteria (e.g., Psychrobacter cryohalolentis, Methanosarcina permafrosti).

FIELD VERIFICATION AND OPERATION CHECKLIST

1. Confirm calibration of the MT3608 boost converter to exactly 5.0V.
2. Check I2C response on the TFT screen (BMP280, ENS160, AHT21, MAX17048).
3. Verify presence of dry silica gel in filter holder2-silica.stl.
4. Confirm proper seating of the 25mm filter without perimeter air leaks.

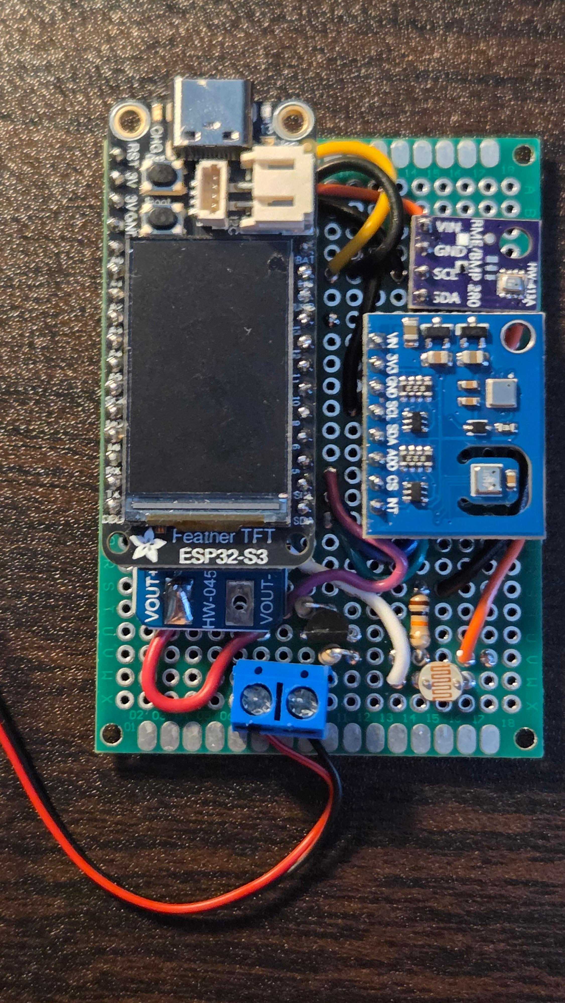
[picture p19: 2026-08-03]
ESP32 Assembly pics/dock.jpg

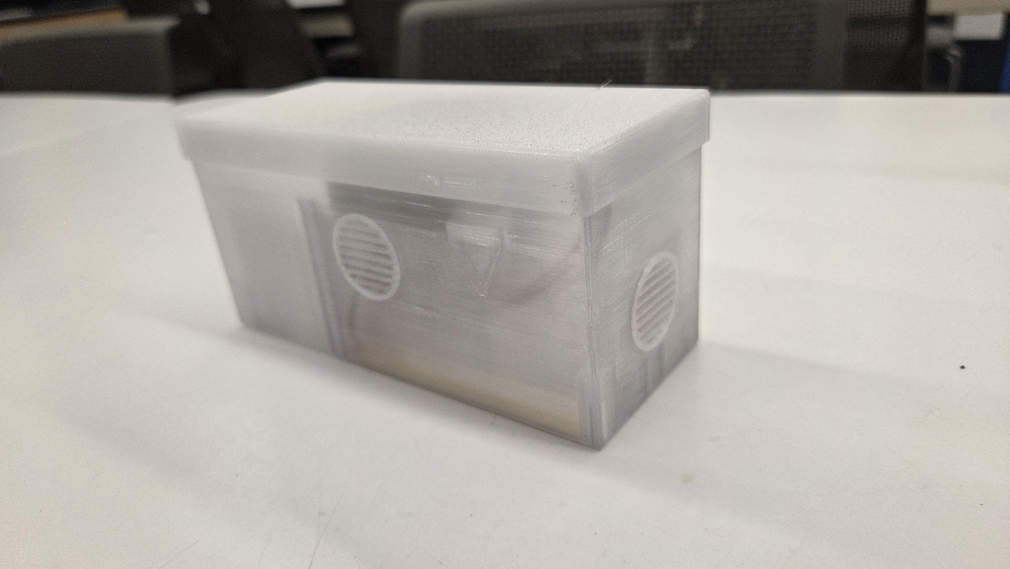
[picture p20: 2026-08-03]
ESP32 Assembly pics/signal-2026-08-01-16-24-59-932_002.jpg

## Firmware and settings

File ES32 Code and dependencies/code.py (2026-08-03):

# code_climate_fsm.py  -  Climate-triggered eDNA sampling FSM
# CircuitPython port of the colleague's MicroPython node.
# Adafruit Feather ESP32-S3 TFT.
#
# What changed from the MicroPython original:
#   machine            -> board + digitalio      (CircuitPython has no 'machine')
#   bme280 (strings)   -> adafruit_bme280 (floats; no more .replace('C',''))
#   machine.I2C(0,...) -> board.STEMMA_I2C()
#   time.ticks_ms/diff -> time.monotonic() seconds
#
# Requires in /lib:  adafruit_bme280

import time
import board
import digitalio
from analogio import AnalogIn
import adafruit_bmp280
import adafruit_ahtx0
import adafruit_ens160

# --- Pin Definitions ------------------------------------------------------
FAN_PIN = board.D5            # gate of the logic-level MOSFET (was GPIO14)
PHOTORESISTOR_PIN = board.A0

# --- Hardware -------------------------------------------------------------
i2c = board.STEMMA_I2C()      # built-in Qwiic; use board.I2C() for header pins
pressure_sensor = adafruit_bmp280.Adafruit_BMP280_I2C(i2c, 0x76)
temp_hum_sensor = adafruit_ahtx0.AHTx0(i2c)
gas_sensor = adafruit_ens160.ENS160(i2c)

fan = digitalio.DigitalInOut(FAN_PIN)
fan.direction = digitalio.Direction.OUTPUT
fan.value = False            # force safe state on boot

light_sensor = AnalogIn(PHOTORESISTOR_PIN)

# --- Target environmental thresholds -------------------------------------
TEMP_MAX_THRESHOLD = 30.0    # do not sample if ambient temp exceeds this (C)
HUM_MIN_THRESHOLD  = 50.0    # only sample if RH >= this (%)
HYSTERESIS_TEMP    = 1.5     # temp offset to damp jitter on shut-down
HYSTERESIS_HUM     = 3.0     # RH offset to damp jitter on shut-down

# --- Timing (seconds; MicroPython used ms) -------------------------------
POLL_INTERVAL     = 5.0      # poll telemetry every 5 s
COOLDOWN_DURATION = 10.0    # 15-minute hardware lock-out
SAMPLING_DURATION = 20.0    # 15-minute hardware lock-out

# --- FSM states -----------------------------------------------------------
STATE_IDLE     = 0
STATE_SAMPLING = 1
STATE_COOLDOWN = 2

current_state  = STATE_IDLE
prev_t         = time.monotonic()
cooldown_start = 0.0
sampling_start = 0.0

print("Glyxon eDNA Node Active [CircuitPython Core]. Commencing climate monitoring...")

while True:
    now = time.monotonic()

    # Non-blocking telemetry poll
    if now - prev_t >= POLL_INTERVAL:
        prev_t = now

        try:
            current_temp = temp_hum_sensor.temperature          # float, degrees C
            current_hum = temp_hum_sensor.relative_humidity     # float, %RH
            current_pressure = pressure_sensor.pressure

            gas_sensor.temperature_compensation = current_temp
            gas_sensor.humidity_compensation = current_hum

            # current_gas_aqi = gas_sensor.AQI
            # current_gas_tvoc = gas_sensor.TVOC
            current_gas_eco2 = gas_sensor.eCO2

            current_ldr = light_sensor.value / 65536 * 100

        except Exception as e:                       # keep the node alive
            print("Error reading Sensors:", e)
            continue

        print("Temp: %.1f C | Hum: %.1f %% | Pressure: %.1f hPa | eCO2: %.1f ppm | Light: %f %% | State: %d" % (current_temp, current_hum, current_pressure, current_gas_eco2, current_ldr, current_state))

        if current_state == STATE_IDLE:
            # Trigger: cool AND humid
            if current_temp <= TEMP_MAX_THRESHOLD and current_hum >= HUM_MIN_THRESHOLD:
                print("-> [BIOLOGICAL ALERT] Target window hit. Commencing capture...")
                fan.value = True
                sampling_start = time.monotonic()
                current_state = STATE_SAMPLING

        elif current_state == STATE_SAMPLING:
            # Shut down (with hysteresis) once conditions drift out of window
            if (current_temp > (TEMP_MAX_THRESHOLD + HYSTERESIS_TEMP) or
                    current_hum < (HUM_MIN_THRESHOLD - HYSTERESIS_HUM)):
                print("-> [NOTICE] Conditions degrading. Aborting sampling run...")
                fan.value = False
                cooldown_start = time.monotonic()
                current_state = STATE_COOLDOWN

            elif time.monotonic() - sampling_start >= SAMPLING_DURATION:
                print("-> Sampling complete. Entering cooldown.")
                fan.value = False
                cooldown_start = time.monotonic()
                current_state = STATE_COOLDOWN

        elif current_state == STATE_COOLDOWN:
            if time.monotonic() - cooldown_start >= COOLDOWN_DURATION:
                print("-> Cooldown complete. Re-entering IDLE surveillance loop.")
                current_state = STATE_IDLE
